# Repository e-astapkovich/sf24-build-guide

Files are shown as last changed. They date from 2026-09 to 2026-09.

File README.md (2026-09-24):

# SF24 — спецификация комплектующих
**Актуальна на сентябрь 2026**

Автор: Евгений Астапкович

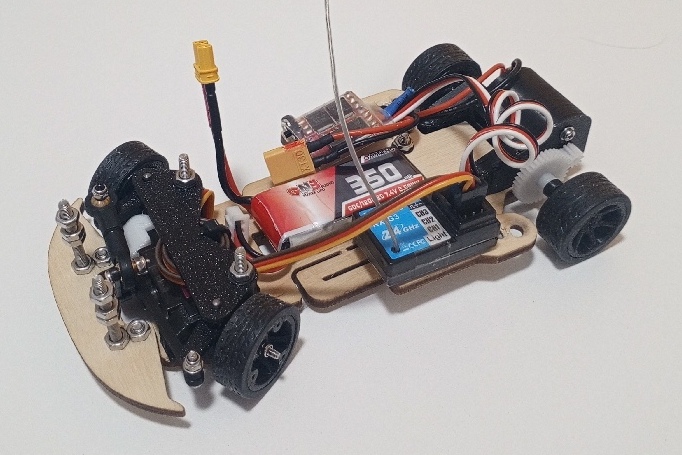
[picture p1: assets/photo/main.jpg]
SF24


## О ПРОЕКТЕ

Актуализированная спецификация для самостоятельной сборки SF24.<br>
Cодержит ссылки на комплектующие с AliExpress и российских магазинов.<br>
В виде таблицы Excel.

Здесь собраны:

- полный список деталей;
- количество деталей на одну машину;
- варианты замен;
- различия между версиями 3D-моделей;
- актуальные ссылки на комплектующие;
- ориентировочная стоимость сборки.

Спецификация подготовлена на основе открытых материалов проекта SF24 и личного опыта сборки.

⚠️***Это неофициальная спецификация.***<br>
Автор этой спецификации не является разработчиком SF24.<br>
Его вклад — актуализация комплектующих, поиск доступных вариантов и подготовка данной спецификации.

## ССЫЛКИ ДЛЯ СКАЧИВАНИЯ

## [📦 Скачать спецификацию SF24 в формате .xlsx](docs/specification/SF24_Specification_BOM___.xlsx)
## [🛞 Скачать STL-модели колесных дисков для силиконовых шин](assets/models/models_of_disks_for_silicone_tires.zip)

## ИНСТРУКЦИЯ ПО СБОРКЕ
## [Скачать инструкцию по сборке (PDF-файл)](docs/INSTRUCTION_SF24_Final_V3.pdf)

## ВИДЕОИНСТРУКЦИЯ
https://rutube.ru/video/feb05db9436182b2d9cb688076ad8728/

## УТОЧНЕНИЕ ПРО АККУМУЛЯТОР
В исходном проекте SF24 предполагается использование аккумулятора 1s формата 18500.<br>
В своей сборке я использовал аккумуляттор 2s. Именно про такой написал в данной спецификации.

Если вы хотите аккумулятор, как в оригинальном проекте, то нужно искать:
- формфактор 18500 **(⚠️ ВНИМАНИЕ! НЕ 18650 - он не поместится на деку!)**
- есть никелевые выводы. Чтобы к ним припаять разъем (⚠️ паять напрямую к аккумулятору не рекомендуется - это может быть опасно, или выведет аккумулятор из строя).

[Ссылка на официальный магазин бренда LiitoKala на Алиэкспресс](https://aliexpress.ru/store/217753)

## Disclaimer
Это независимое руководство, созданное силами сообщества.<br>
SF24, его конструкция и соответствующие модели принадлежат их
соответствующим авторам.<br>
Ссылки, цены и наличие товара могут со временем меняться.

## Контакты автора спецификации
VK: https://vk.ru/e.astapkovich<br>
Telegram: https://t.me/e_astapkovich

## Другие RC-проекты автора
⏳ Coming soon...

## Ссылка на исходный проект
Insane RC / SF24<br>
https://insane-rc.ru/product-category/insane/sf24/*

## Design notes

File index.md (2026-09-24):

# SF24 — спецификация комплектующих
**Актуальна на сентябрь 2026**

Автор: Евгений Астапкович

SF24

## О ПРОЕКТЕ

Актуализированная спецификация для самостоятельной сборки SF24.<br>
Cодержит ссылки на комплектующие с AliExpress и российских магазинов.<br>
В виде таблицы Excel.

Здесь собраны:

- полный список деталей;
- количество деталей на одну машину;
- варианты замен;
- различия между версиями 3D-моделей;
- актуальные ссылки на комплектующие;
- ориентировочная стоимость сборки.

Спецификация подготовлена на основе открытых материалов проекта SF24 и личного опыта сборки.

⚠️***Это неофициальная спецификация.***<br>
Автор этой спецификации не является разработчиком SF24.<br>
Его вклад — актуализация комплектующих, поиск доступных вариантов и подготовка данной спецификации.

## ССЫЛКИ ДЛЯ СКАЧИВАНИЯ

## [📦 Скачать спецификацию SF24 в формате .xlsx](docs/specification/SF24_Specification_BOM___.xlsx)
## [🛞 Скачать STL-модели колесных дисков для силиконовых шин](assets/models/models_of_disks_for_silicone_tires.zip)

## ИНСТРУКЦИЯ ПО СБОРКЕ
## [Скачать инструкцию по сборке (PDF-файл)](docs/INSTRUCTION_SF24_Final_V3.pdf)

## ВИДЕОИНСТРУКЦИЯ
<a href="https://rutube.ru/video/feb05db9436182b2d9cb688076ad8728/">https://rutube.ru/video/feb05db9436182b2d9cb688076ad8728/<a/>

## УТОЧНЕНИЕ ПРО АККУМУЛЯТОР
В исходном проекте SF24 предполагается использование аккумулятора 1s формата 18500.<br>
В своей сборке я использовал аккумуляттор 2s. Именно про такой написал в данной спецификации.

Если вы хотите аккумулятор, как в оригинальном проекте, то нужно искать:
- формфактор 18500 **(⚠️ ВНИМАНИЕ! НЕ 18650 - он не поместится на деку!)**
- есть никелевые выводы. Чтобы к ним припаять разъем (⚠️ паять напрямую к аккумулятору не рекомендуется - это может быть опасно, или выведет аккумулятор из строя).

[Ссылка на официальный магазин бренда LiitoKala на Алиэкспресс](https://aliexpress.ru/store/217753)

## Disclaimer
Это независимое руководство, созданное силами сообщества.<br>
SF24, его конструкция и соответствующие модели принадлежат их
соответствующим авторам.<br>
Ссылки, цены и наличие товара могут со временем меняться.

## GitHub проекта:
<a href="https://github.com/e-astapkovich/sf24-build-guide">
    https://github.com/e-astapkovich/sf24-build-guide
</a>

## Контакты автора спецификации
VK: <a href="https://vk.ru/e.astapkovich">https://vk.ru/e.astapkovich</a>
<br>
Telegram: <a href="https://t.me/e_astapkovich">https://t.me/e_astapkovich</a>

## Другие RC-проекты автора
⏳ Coming soon...

## Ссылка на исходный проект
Insane RC / SF24<br>
<a href="https://insane-rc.ru/product/sf24-kit/">https://insane-rc.ru/product/sf24-kit/</a>

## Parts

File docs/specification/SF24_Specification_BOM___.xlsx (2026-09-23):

 | НАИМЕНОВАНИЕ | ОПИСАНИЕ | ПРИМЕЧАНИЕ | К-ВО | ССЫЛКА 2026 | ДЛЯ ПОИСКА Aliexpress | ЦЕНА, лот | Кол-во в лоте | ЦЕНА единицы | СУММА ДЛЯ НАБОРА
ФАНЕРА | Цена зависит от исполнителя, и может очень сильно различаться
 | Шасси | SF24_W001_Main Chassis_V2 | V3 - с большим количеством вырезов | 1
 | Верхняя плата | SF24_W002_Upper Frame_V2 |  | 1
 | Бампер | SF24_W003_Bumper |  | 1
3D-ПЕЧАТЬ | Цена зависит от исполнителя, и может очень сильно различаться
 | Моторама | SF24_P001-10_Motormount_V5 | V4 - с прорезями под гайку, неудобно | 1
 | Левый кулак | SF24_P003L_Front Hub L_V4 | V3 - без углубления под пружину | 1
 | Правый кулак | SF24_P003R_Front Hub R_V4 | V3 - без углубления под пружину | 1
 | Распорка передней подвески | SF24_P005_Suspension TowerV3 | V4 - с площадкой для транспондера | 1
 | Крепление сервопривода левое | SF24_P006_Suspension Holder L_V3 |  | 1
 | Крепление сервопривода правое | SF24_P006_Suspension Holder R_V3 |  | 1
 | Рулевая тяга | SF24_P007_SteeringRod |  | 1
 | Стойки передней распорки | SF24_SH3x7x14 |  | 2
 | Стойки верхней платы | SF24_SH3x7x3 |  | 2
 | Передние диски | Диск_передний.stl (дополнительный набор моделей) | SF24_P004_FrontWheelV4 (ДЛЯ МИКРОПОРЫ) | 2
 | Задние диски | Диск_задний.stl, Проставка_оси.stl (дополнительный набор моделей) | SF24_P002_RearWheelV4 (ДЛЯ МИКРОПОРЫ) | 2
ШИНЫ |  |  |  |  |  |  | 440.00 |  |  | 440.00
 | КОМПЛЕКТ резины СИЛИКОН | Шины из силикона (нужны диски под эти шины) | ЛИБО СИЛИКОН, ЛИБО МИКРОПОРА | 1 | https://aliexpress.ru/item/1005004171823853.html | Racing Pattern Tire Skin 22mm Wheel WLtoys KYOSHO 1/28 RC Car | 440 | 1 | 440 | 440.00
 | Передняя резина МИКРОПОРА | Шины из пористой резины | ЛИБО СИЛИКОН, ЛИБО МИКРОПОРА | 2 | https://rezina74.ru/catalog/tekhplastina/plastina-poristaya/102309/
 | Задняя резина МИКРОПОРА | Шины из пористой резины | ЛИБО СИЛИКОН, ЛИБО МИКРОПОРА | 2 | https://rezina74.ru/catalog/tekhplastina/plastina-poristaya/102309/
МЕХАНИКА |  |  |  |  |  |  | 1892.00 |  |  | 1325.96
 | Ведомая шестерня (спур) | 0.5M 38T, отв 2мм (диам до 20мм) |  | 1 | https://aliexpress.ru/item/32964210019.html | gear 0.5M | 115 | 10 | 11.5 | 11.50
 | Ведущая шестерня (пиньон) | 0.5M 10T, отв 2мм | длинная версия https://aliexpress.ru/item/32963402664.html | 1 | https://aliexpress.ru/item/1005009793159581.html?mixer_rcmd_bucket_id=controlRu1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 | gear 0.5M | 113 | 50 | 2.26 | 2.26
 | Шаровые наконечники | оба диаметра 2мм (отверстие под тягу, и отверстие в шарике) | Можно использовать 3мм. Но тогда в МЕТИЗАХ нужно взять установочный винт тоже М3 | 2 | https://aliexpress.ru/item/1005009843752666.html?sku_id=12000050339099361 | RC Nylon Rod End Ball Joints | 364 | 10 | 36.4 | 72.80
 | Пружины | наруж диам 3мм, длина 5мм, диам проволоки 0.2 - 0.5мм |  | 2 | https://aliexpress.ru/item/1005009926585902.html?sku_id=12000050597318786 | springs 3 mm | 130 | 10 | 13 | 26.00
 | Ось задняя | Штифт 3х75 |  | 1 |  | steel rod bar | 200 | 1 | 200 | 200.00
 | Пин передней подвески (кинг пин) | Штифт 2x22 |  | 2 | https://aliexpress.ru/item/1005004510671330.html?sku_id=12000029420752239 | cylindrical pin steel | 104 | 20 | 5.2 | 10.40
 | Подшипники MF62ZZ |  |  | 4 | https://aliexpress.ru/item/32880777629.html?sku_id=12000033773143057 | Flange Bearing | 137 | 2 | 68.5 | 274.00
 | Подшипники MF63ZZ |  |  | 2 | https://aliexpress.ru/item/32880777629.html?sku_id=12000033773143038 | Flange Bearing | 129 | 2 | 64.5 | 129.00
 | Кузов |  | Обычно продается не крашенный. На Али есть крашенные для Wltoys k969/989. По длине немного не подходят, нужно подрезать арки | 1 | http://slotracingshop.com/catalog/kuzova-klassa-chajnik-124/ | rc car shell body 1/28 1/24 | 300 | 1 | 300 | 300.00
 | Краска для кузова | Tamiya PS | Только серия PS подходит для лексана!!! | 1 | https://www.ozon.ru/seller/chenguane/ |  | 300 | 1 | 300 | 300.00
ЭЛЕКТРОНИКА |  |  |  |  |  |  | 1857.00 |  |  | 1857.00
 | Аккумулятор | 2s | хорошо подходит по размеру Gaoneng 380mAh или 350mah | 1 | https://www.ozon.ru/product/akkumulyator-li-po-gnb-380mah-2s1p-7-6v-hv-90c-5173858619/?sh=jYizFu24Fw |  | 850 | 1 | 850 | 850.00
 | Регулятор | 30A | Ссылка от Зуйкова | 1 | https://aliexpress.ru/item/1005010500766006.html?sku_id=12000052605243905 | RC ESC 30A Brushed | 282 | 1 | 282 | 282.00
 | Электромотор | 130 класс, 3500kv (или 2500kv, если нужно по регламенту) | ВНИМАНИЕ!!! Покупать только с крепёжными отверстиями! Моторы этого размера часто не имеют крепёжных отверстий | 1 | https://aliexpress.ru/item/1005005108677293.html?sku_id=12000044573200626 |  | 325 | 1 | 325 | 325.00
 | Сервопривод | MG90 на 180 градусов | Есть в Челябинске в Проконтакт | 1 | https://procontact74.ru/ustanovochnye-izdeliya/29-elektrodvigateli-reduktory/291-reduktory-servoprivody/servoprivod-mg90s-29106/ |  | 400 | 1 | 400 | 400.00
АППАРАТУРА |  |  |  |  |  |  | 3000.00 |  |  | 3000.00
 | Аппаратура + приёмник | Turbo Racing P32 (или любая другая на свой вкус) |  | 1 | https://aliexpress.ru/item/1005002312757685.html?sku_id=12000020032330003 | Turbo Racing P32 | 3000 | 1 | 3000 | 3000.00
МЕТИЗЫ | Отмеченное зелёным есть в Челябинске, магазин "Нержавейка", Труда 175 |  |  |  |  |  | 0.00
 | Купить можно в разных местах, цена может сильно отличаться. На Алиэкспресс продаются большими лотами 10-50 шт.
 | Гайка M2 | A2 DIN 934 | Есть RC вариант https://aliexpress.ru/item/1005008840628072.html?sku_id=12000046902883616 | 4 |  | DIN 934
 | Гайка M3 | A2 DIN 934 |  | 24 |  | DIN 934
 | Гайка с нейлоном M2 | A2 DIN 985 |  | 4 |  | DIN 985
 | Шайба М2x5x0.5 |  | В "Нержавейке" есть, но гораздо тоньше… | 2 |  | shim m2
 | Шайба М3х5х0.3 |  |  | 2 |  | shim m3
 | Шайба М3х7х0.5 |  |  | 6
 | Винт с полукруглой 2x6 | A2 DIN 7985 |  | 5 |  | DIN 7985
 | Винт с полукруглой 2x10 | A2 DIN 7985 |  | 2 |  | DIN 7985
 | Винт с полукруглой 2x16 | A2 DIN 7985 |  | 1 |  | DIN 7985
 | Винт ПОТАЙ 2x6 | A2 DIN 965 |  | 2 |  | DIN 965
 | Винт ПОТАЙ 2x20 | A2 DIN 965 |  | 2 |  | DIN 965
 | Винт ПОТАЙ 3x8 | A2 DIN 965 |  | 4 |  | DIN 965
 | Винт ПОТАЙ 3x10 | A2 DIN 965 |  | 2 |  | DIN 965
 | Винт ПОТАЙ 3x16 | A2 DIN 965 |  | 2 |  | DIN 965
 | Винт ПОТАЙ 3x20 | A2 DIN 965 |  | 2 |  | DIN 965
 | Винт ПОТАЙ 3x30 | A2 DIN 965 |  | 4 |  | DIN 965
 | Винт Установочный 2x10 | A2 DIN 914 |  | 1 |  | DIN 914
SF24 — спецификация комплектующих.
Актуальные ссылки и цены проверены: сентябрь 2026
Это неофициальная спецификация.
Подготовил: Евгений Астапкович
https://github.com/e-astapkovich/sf24-build-guide
Исходный проект: Insane RC / SF24
https://insane-rc.ru/product-category/insane/sf24/

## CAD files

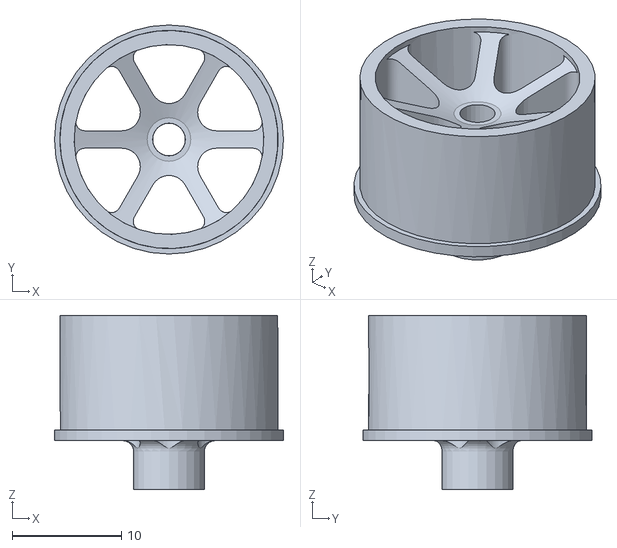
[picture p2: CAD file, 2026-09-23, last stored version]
assets/models/Диск_задний.stl
21.0 x 21.0 x 16.0

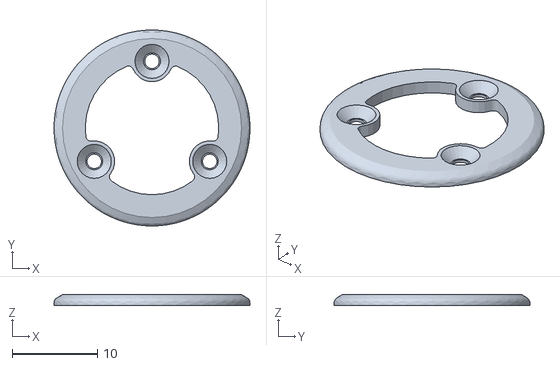
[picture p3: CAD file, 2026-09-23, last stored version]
assets/models/Бортик диска 39.5.stl
23.0 x 23.0 x 1.30

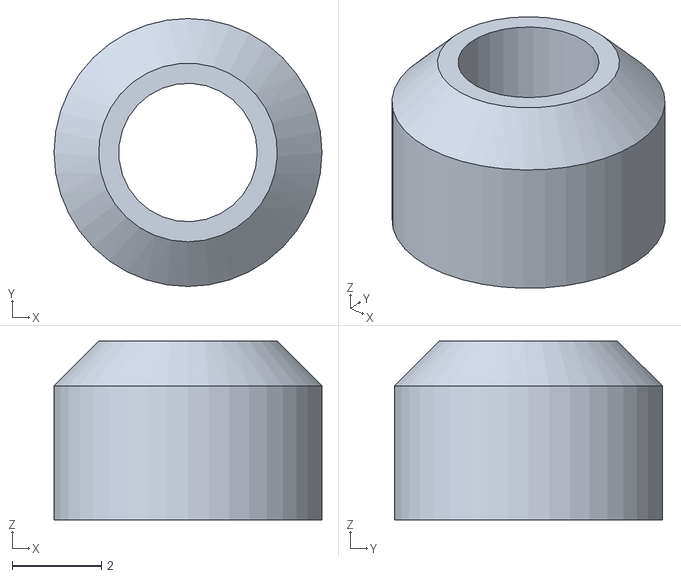
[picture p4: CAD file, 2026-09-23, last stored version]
assets/models/Проставка оси 4мм.stl
6.00 x 6.00 x 4.00

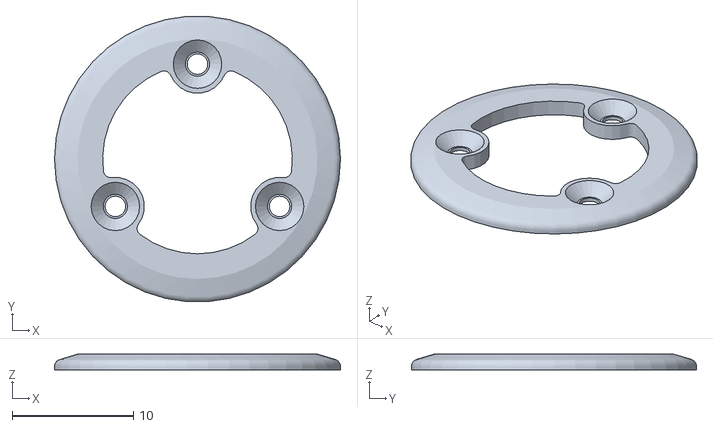
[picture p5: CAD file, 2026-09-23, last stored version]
assets/models/Бортик диска 39_6.stl
23.6 x 23.5 x 1.30

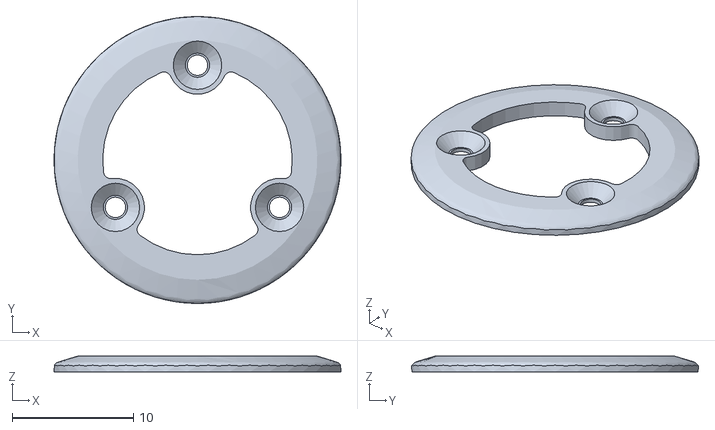
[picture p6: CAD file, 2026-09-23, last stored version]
assets/models/Бортик диска 39_7.stl
23.7 x 23.7 x 1.30

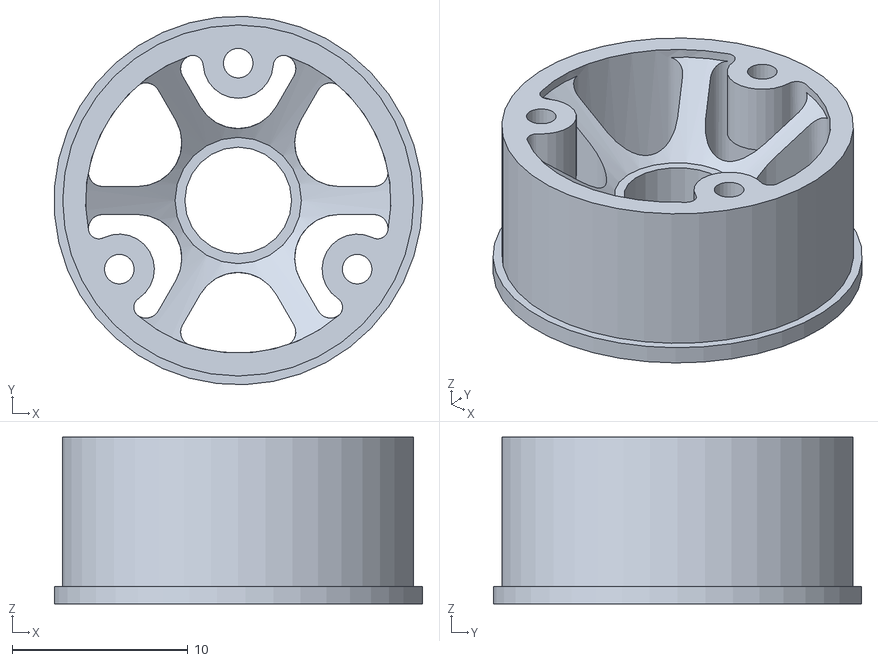
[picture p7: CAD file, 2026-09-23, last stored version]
assets/models/Диск_передний.stl
21.0 x 21.0 x 9.50

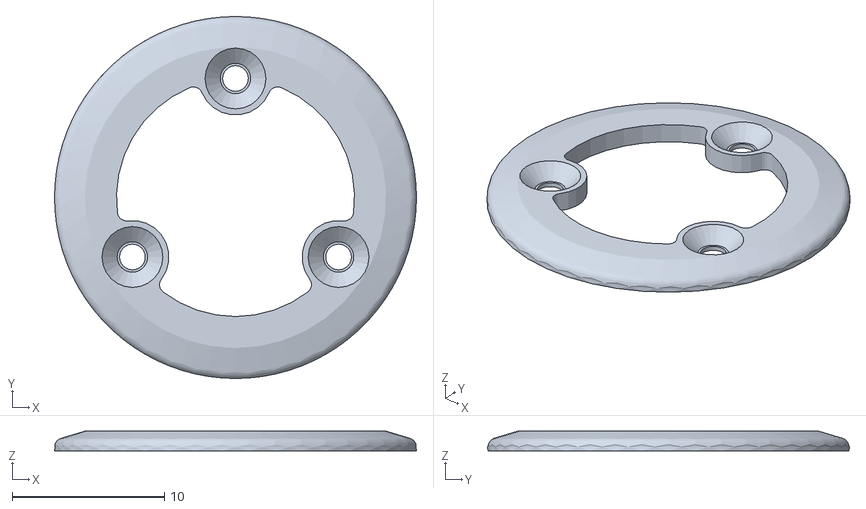
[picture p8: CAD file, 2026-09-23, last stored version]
assets/models/Бортик диска 39.8.stl
23.8 x 23.8 x 1.30

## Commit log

2026-09-23 add specification in .xlsx format
    [SF24_Specification_BOM___.xlsx]
2026-09-23 replace specification from main directory
    [SF24_Specification_BOM___.xlsx]
2026-09-23 assets: add models for wheels
    [Бортик диска 39.5.stl, Бортик диска 39.8.stl, Бортик диска 39_6.stl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]
2026-09-23 docs(readme): add battery info
2026-09-23 chore: group disks models to single archive
    [Бортик диска 39.5.stl, Бортик диска 39.8.stl, Бортик диска 39_6.stl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]
